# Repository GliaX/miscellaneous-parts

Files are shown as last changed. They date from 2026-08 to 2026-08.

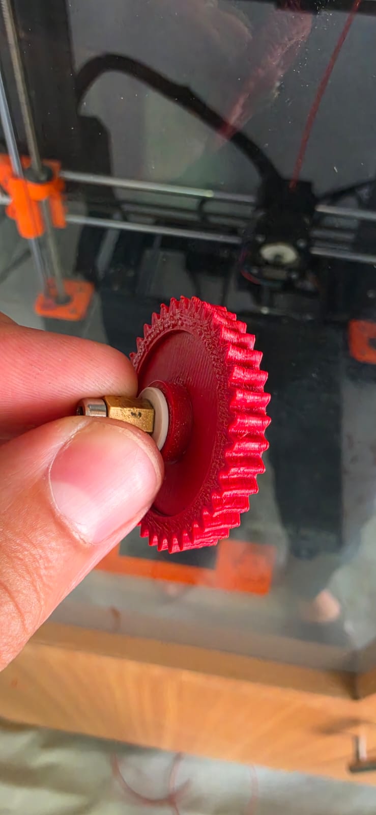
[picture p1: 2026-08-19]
Infusion_pump_gear/Media/Visual_test.jpeg

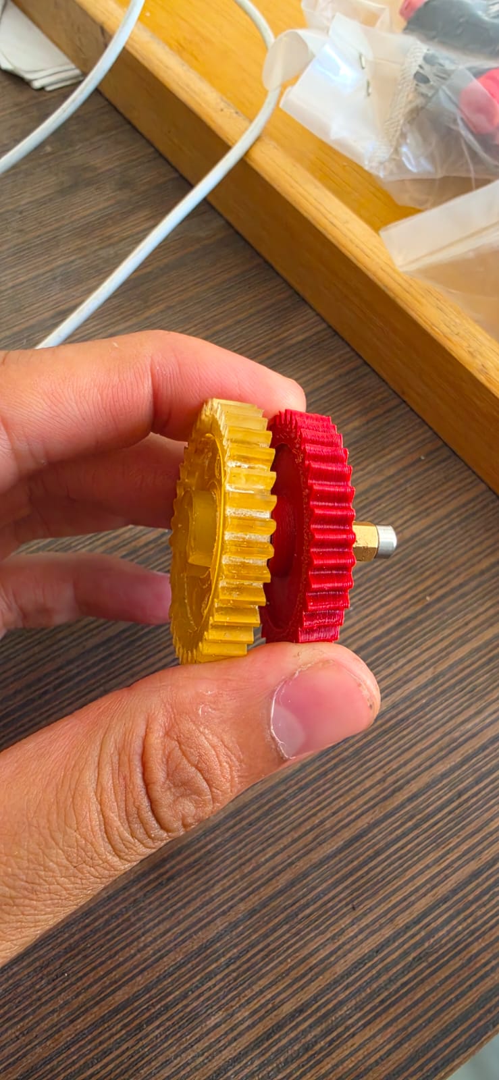
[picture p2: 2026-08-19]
Infusion_pump_gear/Media/visual_test2.jpeg

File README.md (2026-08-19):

# Open-Source 3D-Printed Medical Replacement Components

This repository serves as a centralized, open-source registry for 3D-printed medical device replacement components. It is designed to assist biomedical engineers and clinical technicians in sourcing, manufacturing, and validating critical spare parts for medical equipment—especially in resource-constrained environments or crisis zones where supply chains are disrupted.

Every component listed in this repository represents a localized engineering solution aimed at reducing clinical downtime and restoring life-saving diagnostic and therapeutic machinery to active service.

---

## 📂 Repository Structure

The repository is organized into independent, self-contained project directories.

```text
.
├── 📁 infusion-pump-gear/             # Project 1: Syringe Pump Drivetrain Replacement
│   ├── 📁 design-files/              # FreeCAD (.FCStd)
│   ├── 📁 print-files/               # Production-ready .stl
│   ├── 📁 docs-and-manuals/          # Equipment user/service manuals (PG-801D)
│   ├── 📁 media/                     # Inspection photographs and deployment videos
│   └── 📄 README.md                  # In-depth technical guide & validation workflow
│
└── 📄 README.md                      # This root registry overview documentation
```

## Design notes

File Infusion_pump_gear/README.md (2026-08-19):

# 3D-Printed Infusion Pump (PG-801D) Drive Gear Replacement

> [!WARNING]
> **WARNING: DO NOT USE THIS PART YET**
> This model is currently in testing and refinement. It is NOT ready for clinical or deployment use.

## 1. Project Overview
This open-source medical hardware project addresses a critical clinical bottleneck: the downtime of **PG-801D Infusion Pumps** due to the premature wear and mechanical failure of the primary drive gear. 

An infusion pump is a life-critical medical device that delivers fluids, nutrients, or medications (such as chemotherapy, hormones, or antibiotics) into a patient’s body in controlled amounts. In resource-constrained clinical settings—such as hospitals in Gaza—the wear and tear of minor plastic gears often renders these expensive machines entirely inoperable, as replacement parts are difficult to source locally.

### The Problem
* **Frequent Component Wear:** The original injection-molded plastic gear suffers from tooth erosion over extended periods of continuous operation.
* **Low Tolerance for Error:** Even a minor slippage on these teeth results in precise sensor warnings (such as flow error/blockage alarms), triggering an immediate machine shutdown to ensure patient safety.
* **Widespread Downtime:** Dozens of infusion pumps are currently out of service in local medical facilities solely due to this single faulty component.

### The Solution
By FreeCAD and Fused Deposition Modeling (FDM) 3D printing with (ABS), we developed an exact physical replica of the primary drive gear. This repository provides the trial design file, print file(STL,3MF), media and user manual.

# 2. Device & Component Information
* **Target Device:** Infusion Pump PG-801D (Syringe/Volumetric Driver)
* **Part Function:** Primary drive gear for the main rotary drivetrain.
* **Mechanical Role:** Transfers continuous rotational torque directly from the main electric stepper motor to the lead screw (threaded drive shaft). As the gear rotates, it drives the lead screw, which translates rotational force into linear motion to push the syringe plunger at precise, micro-controlled flow rates.
* **Failure Mechanism:** Constant mechanical stress and frictional fatigue lead to tooth thinning and rounding. Any minor play or loss of motion transmission stops the lead screw, triggering immediate sensor faults on the device.

## 3. Engineering Process
To ensure the printed part functions identically to the manufacturer's original specification, the following engineering workflow was executed:

1. **Dimensional Analysis & Metrology:** Detailed caliper and micrometer measurements of the original (worn) gear were taken to define pitch circle diameter, outer diameter, tooth profile, shaft bore size, and keyway features.
2. **Parametric CAD Modeling (FreeCAD):** 
   * Formulated the exact gear module and tooth count within FreeCAD.
   * Modulated the core mounting hub to house the original locking brass screw insert.
   * Exported the final parametric model into standard interchange formats (`.FCStd`, `.stl`).
3. **Slicing and Flow Analysis:** Used PrusaSlicer to set up optimal layer bonding and wall strength, packaging the finalized print settings into a portable `.3mf` file.

---

## 4. Manufacturing Specifications

 Material Selection
* **Recommended Filament:** **ABS or PETG **
* **Why ABS?** ABS provides high impact resistance, dimensional stability under continuous torque.
* **Why PETG?** PETG offers excellent layer adhesion, high toughness, and ease of printing with low thermal shrinkage.

<h1 align="center" style="color:red;">⚠️ WARNING: DO NOT USE THIS PART YET ⚠️</h1>
<h3 align="center" style="color:red;">This model is currently in testing and refinement. It is NOT ready for clinical or deployment use.</h3>

### Recommended Slicer Settings ABS
| Parameter | Value | Details |
| :--- | :--- | :--- |
| **Nozzle Temperature** | **250°C** | High temperature ensures optimal inter-layer adhesion to prevent tooth shearing under torque. |
| **Bed Temperature** | **105°C** | Essential to prevent ABS warping on the print bed. |
| **Infill Percentage** | **100% (Solid)** | Solid infill is mandatory to maximize mechanical shear resistance of the gear teeth. |
| **Layer high**| **0.2** | Provides an optimal outer boundary definition. |
| **Support Material** | **Yes / Enabled** | Required to cleanly support the central overhanging mounting hub and gear face profile. |
| **Enclosure** | **Recommended** | An enclosed printer chamber is highly recommended to control ambient temperatures and eliminate ABS warping. |

### Recommended Slicer Settings PETG
| Parameter | Value | Details |
| :--- | :--- | :--- |
| **Nozzle Temperature** | **230°C** | 
| **Bed Temperature** | **85°C** | 
| **Infill Percentage** | **100% (Solid)** | Solid infill is mandatory to maximize mechanical shear resistance of the gear teeth. |
| **Layer high**| **0.2** | Provides an optimal outer boundary definition. |
| **Support Material** | **Yes / Enabled** | Required to cleanly support the central overhanging mounting hub and gear face profile. |

## 5. Validation & Functional Testing
Before deploying the manufactured gear into a clinical environment, each printed unit undergoes a strict multi-tier quality control protocol:
For details about tests, see the [Testing Protocol](Quality_control/README.md).

```
[3D Print Completed] 
       │
       ▼
 1. Visual Inspection  ───► Check tooth profiles for stringing, warping, or defects

       │
       ▼
 2. Hub & Thread Test  ───► Insert the locking brass screw to verify smooth, clean rotation
       │
       ▼
 3. Benchtop Testing   ───► Install inside PG-801D and run non-clinical tests (water-pumping)
       │
       ▼
[Clinical Approval]

```

## Medical & Safety Disclaimer

This design is provided "as is" for educational, experimental, and humanitarian evaluation only. The author accepts no responsibility or liability for any direct, indirect, incidental, or consequential damages, injuries, or device failures resulting from the manufacture, testing, or clinical use of this design. Use and deployment are entirely at the user's own risk.

---
## License
This design is shared under the [CERN Open Hardware Licence Version 2 - Permissive (CERN-OHL-P)](LICENSE.md).see the LICENSE file for details.

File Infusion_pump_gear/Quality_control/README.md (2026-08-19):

# Design Intent & Quality Control - Infusion Pump Gear

## 1. Primary Function & Purpose
- **Application:** Precise torque and rotational motion transfer within the infusion pump mechanism.
- **Critical Requirement:** Smooth engagement with zero tooth slipping to maintain accurate, controlled liquid delivery.

## 2. Material Selection & Rationale
- **Approved Materials:** ABS or PETG.
- **Rationale:** Selected for high mechanical strength, fatigue tolerance, and low friction wear resistance required for continuous pump operation.

## 3. Manufacturing Specifications (FDM / 3D Printing)
- **Print Orientation:** Flat on the print bed (aligns layer orientation perpendicular to tooth shear force vectors for maximum strength).
- **Infill:** 100% Solid (Ensures maximum core density and prevents internal structural collapse under torque).
- **Wall Thickness / Shells:** 5 Perimeters (Horizontal Shells) to ensure the gear teeth consist of solid extruded lines rather than infill pattern gaps.
- **Layer Height:** 0.2 mm (Optimal balance between dimensional resolution of tooth profiles and inter-layer adhesion strength).

## 4. Quality Control & Inspection Checklist

### Phase 1: Bench & Mechanical Verification
- [ ] **Dimensional Tolerance:** Verify pitch and outer diameter within ±0.1 mm accuracy using calipers.
- [ ] **Tooth Surface Finish:** Inspect gear teeth faces for zero stringing, blobs, or under-extrusion artifacts.
- [ ] **Shaft Alignment Test:** Mount on the motor/pump shaft to confirm a secure, precise fit without mechanical play or slippage.
- [ ] **Manual Mesh Test:** Manually rotate in mesh with the mating gear inside the pump housing to verify smooth, continuous rotation without binding.

### Phase 2: Dynamic Functional Testing (Validation Stage)
- [ ] **Fluid Dispensing Accuracy Test:** Run an active pumping cycle to discharge **500 mL of water** over a targeted timeframe. Verify that the output volume and flow rate match calibration specs with zero mechanical slippage or timing errors under continuous load.

For more detailes about tests, see the [Testing Protocol](testing-protocol.md).

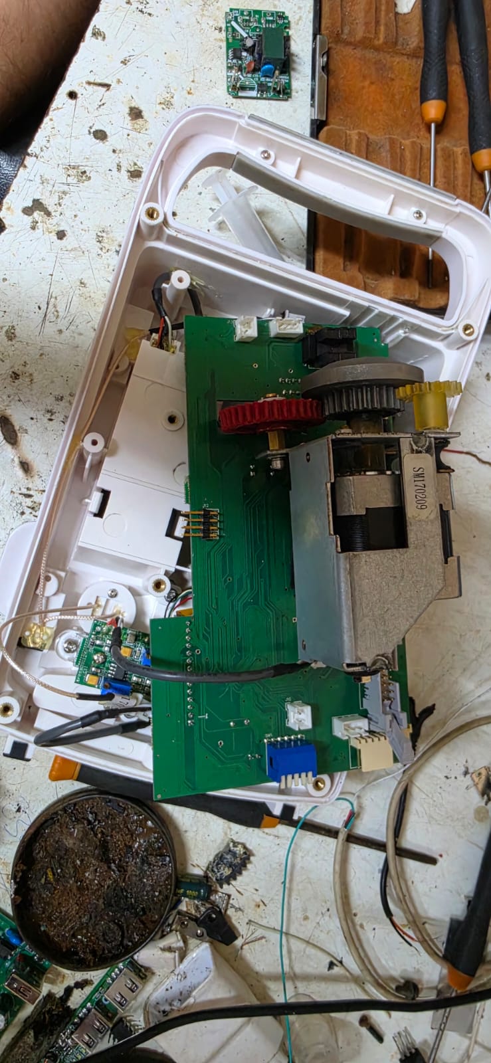
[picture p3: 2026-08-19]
Infusion_pump_gear/Media/Assemple_on_IP.jpeg

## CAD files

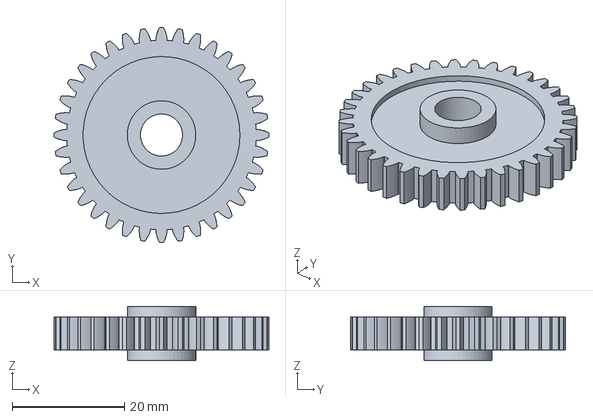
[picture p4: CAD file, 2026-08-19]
Infusion_pump_gear/Design_files/Infusion_pump_gear.FCStd
38.4 x 38.4 x 9.70 mm

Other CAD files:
Infusion_pump_gear/print_files/infusion_pump_gear_ABS.3mf
Infusion_pump_gear/print_files/infusion_pump_gear.stl
Infusion_pump_gear/print_files/infusion_pump_gear_PETG.3mf

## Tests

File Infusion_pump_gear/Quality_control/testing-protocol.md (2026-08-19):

# 🧪 Testing & Validation Protocol - Infusion Pump Gear (PG-801D)

This document outlines the standard operating procedures for verifying and validating the 3D-printed infusion pump drivetrain gear.

---

## 1. Visual & Dimensional Inspection (Static Phase)

- [ ] **Dimensional Tolerance:** Verify pitch and outer diameter within ±0.1 mm accuracy using calipers.
- [ ] **Tooth Surface Finish:** Inspect gear teeth faces for zero stringing, blobs, or under-extrusion artifacts.
- [ ] **Shaft Alignment Test:** Mount on the motor/pump shaft to confirm a secure, precise fit without mechanical play or slippage.
- [ ] **Manual Mesh Test:** Manually rotate in mesh with the mating gear inside the pump housing to verify smooth, continuous rotation without binding.

---

## 2. Dynamic Functional Testing (Device Phase)

Once the visual inspection is passed, install the gear into the **PG-801D Infusion Pump** unit to execute active operational testing under load.

### Required Test Equipment & Setup
* **Target Device:** PG-801D Infusion Pump Unit
* **Fluid Source:** 500 mL IV Solution Bag (Normal Saline / Water)
* **Administration Set:** Standard Infusion / IV Tubing Set
* **Output Measurement:** 500 mL Calibrated Graduated Cylinder / Measuring Vessel

### Operating Parameters
| Parameter | Target Specification |
| :--- | :--- |
| **Test Equipment** | PG-801D Infusion Pump |
| **Test Fluid** | 500 mL Normal Saline / Water|
| **Flow Rate Setting** | 100 mL/hr |
| **Target Runtime** | ~5 Hours |

### Test Procedure
1. Install the gear into the drivetrain assembly and secure housing cover.
2. Set up a calibrated measuring cylinder at the pump discharge tube.
3. Initiate the pumping cycle at **100 mL/hr** and start the timer.
4. Periodically inspect for abnormal mechanical noise, motor heat, or gear tooth wear.
5. Record total discharged volume at completion and compare against target volume.

---

## 3. Historical Test Execution Logs

| Test ID | Date | Tested By | Setup / Target | Measured Output | Flow Accuracy | Result | Notes & Observations |
| :--- | :--- | :--- | :--- | :--- | :--- | :--- | :--- |
| **TEST-01** | 2026-07-22 | Amer | 300 mL/h (1 Hr) | 260 mL/h | 86.6% (-40 mL/h) | ⚠️ Needs improve  |  |

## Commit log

2026-10-05 Add FUJI CR Cassette_Clip_Slicer components and update registry README in the main file
    [CassetteClip-Body.3mf, CassetteClip-Body.stl, CassetteClip.FCStd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]
2026-10-18 Update CR Cassette README file
    Removed warning about clinical testing status and refined material optimization details.
2026-10-29 Added the current version of the blood pressure cuff repair and manufacturing kits
